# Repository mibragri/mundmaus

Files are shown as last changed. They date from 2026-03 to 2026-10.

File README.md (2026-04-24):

# MundMaus

**Mundgesteuerte Spieleplattform fuer Menschen mit Tetraplegie.**

Ein ESP32 mit Joystick und Drucksensor steuert browserbasierte Spiele — pusten statt klicken, Joystick statt Maus. Kein Internet, keine App. Nur WLAN und ein Browser.

Kosten: ~25 EUR | Aufbauzeit: ~30 Minuten | Nur der Drucksensor muss geloetet werden

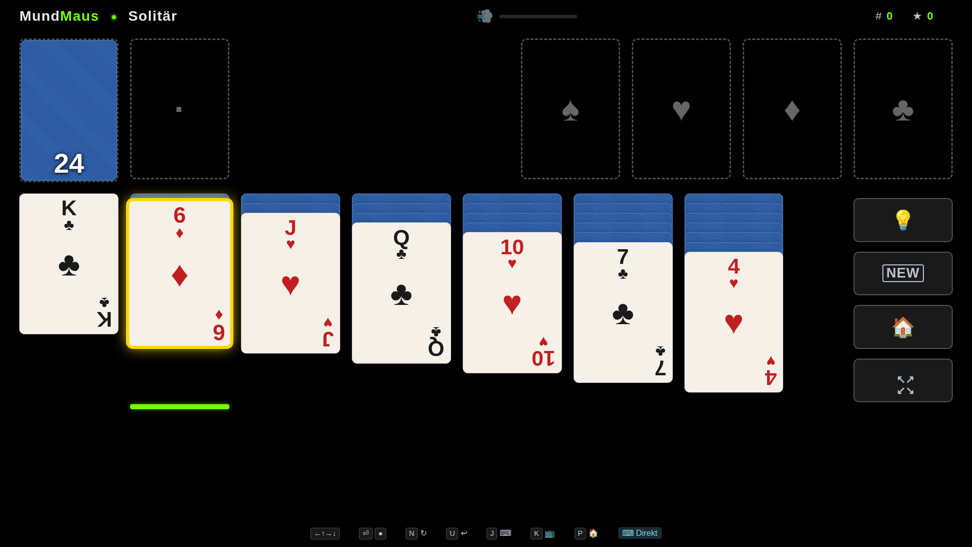
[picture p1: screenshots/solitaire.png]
Solitaire
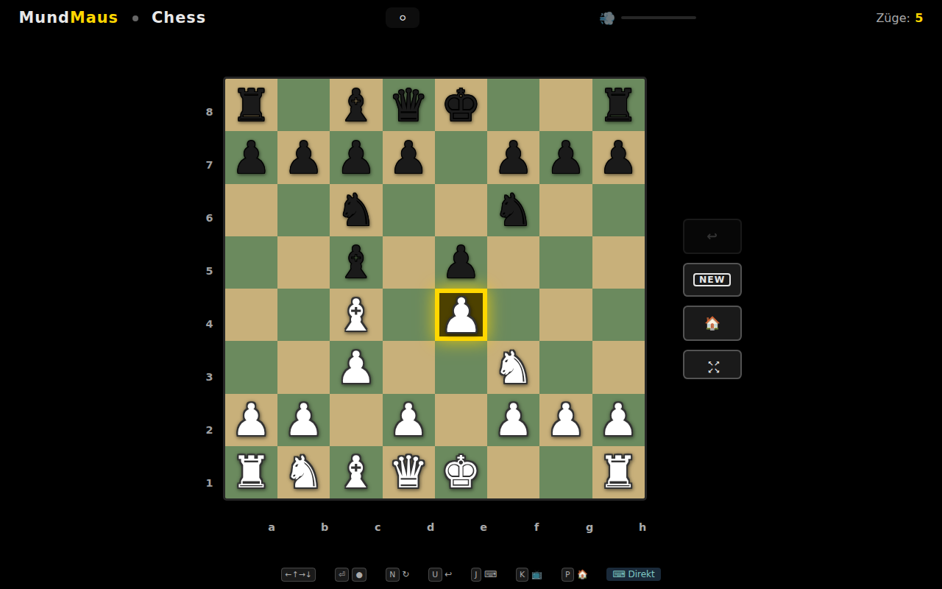
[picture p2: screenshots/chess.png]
Chess
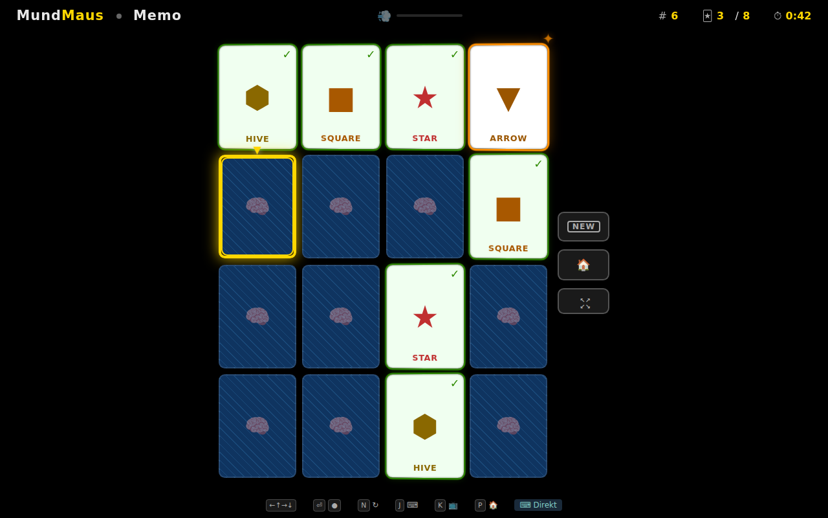
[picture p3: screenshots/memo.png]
Memo
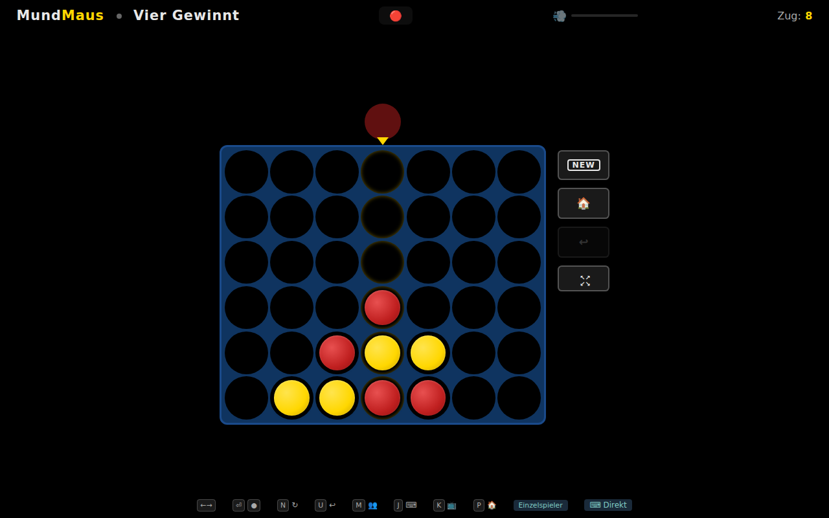
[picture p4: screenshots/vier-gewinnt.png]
Vier Gewinnt
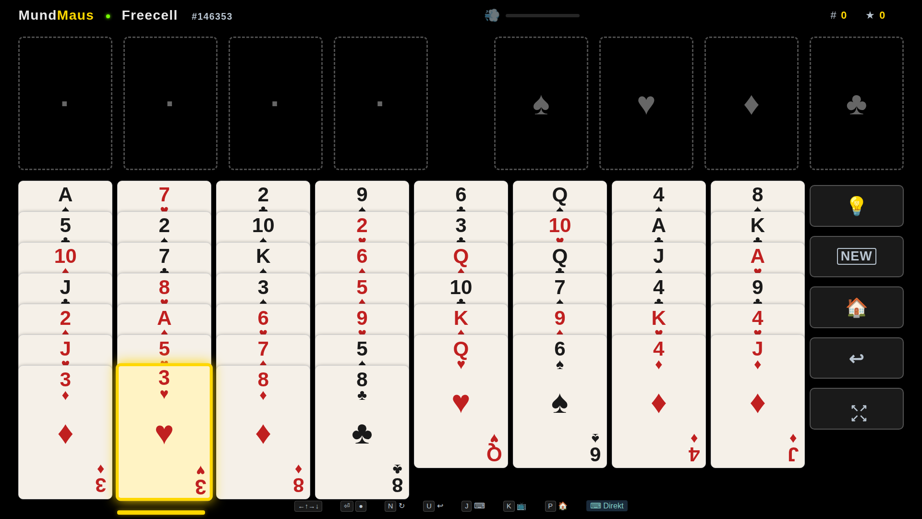
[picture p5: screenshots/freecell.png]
Freecell
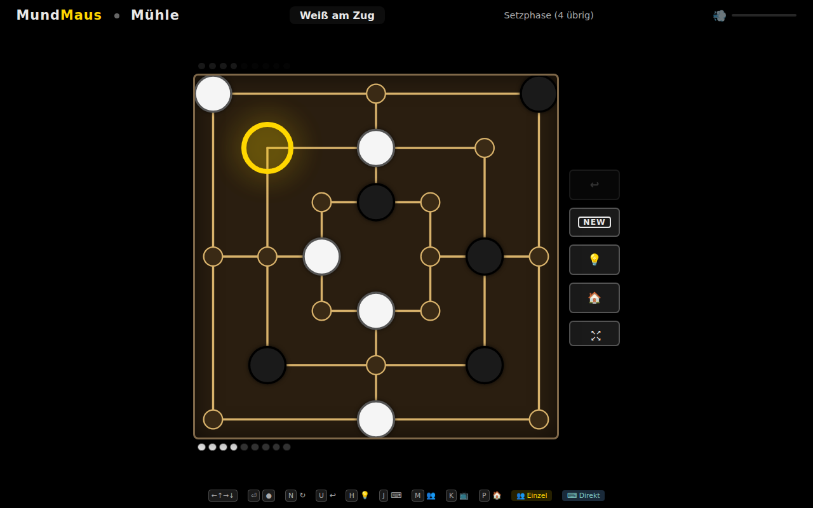
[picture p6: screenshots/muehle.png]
Mühle
     

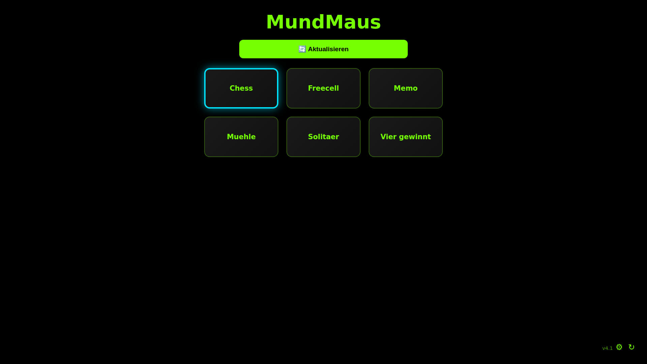
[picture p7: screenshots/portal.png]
Portal
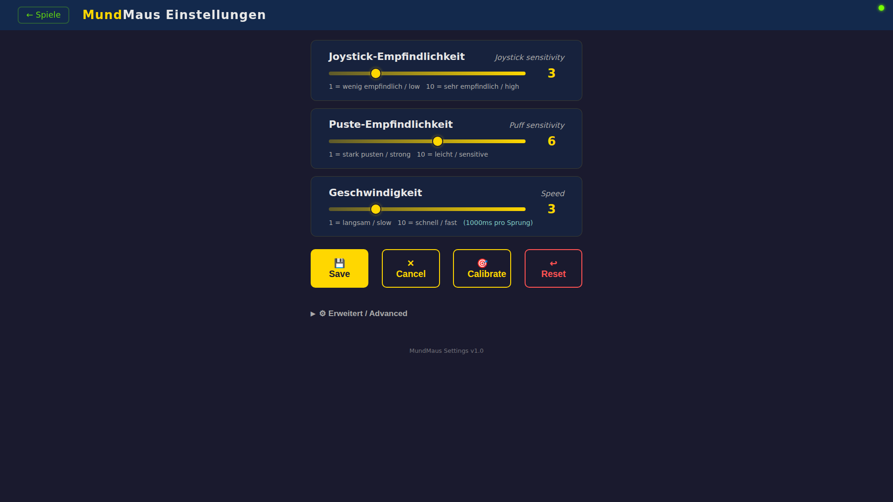
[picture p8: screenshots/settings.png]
Settings
 

## So funktioniert es

1. ESP32 liest Joystick (Lippe/Zunge) + Drucksensor (Pusten)
2. Sendet Befehle per WebSocket an den Browser
3. Browser zeigt Kartenspiele auf TV/Monitor
4. Alles laeuft lokal — kein Internet noetig

```
   Joystick ──┐
               ├── ESP32 ──── WiFi ──── Browser (TV/Monitor)
Drucksensor ──┘                          6 Spiele (Solitaer, Schach, Freecell, Memo, Muehle, Vier gewinnt)
```

## Spiele

| Spiel | Beschreibung |
|---|---|
| **Solitaire** | Klondike mit Undo, Auto-Solve, 3 Schwierigkeitsstufen |
| **Schach** | Gegen Computer, 4 Schwierigkeitsstufen |
| **Memo** | Memory-Spiel, 4 Feldgroessen |
| **Vier Gewinnt** | Connect Four gegen KI, 3 Schwierigkeitsstufen |
| **Freecell** | Freecell Solitaire mit Supermove und Auto-Complete |
| **Mühle** | Nine Men's Morris gegen KI, 3 Schwierigkeitsstufen, mit Multiplayer |

Alle Spiele sind barrierefrei: farbenblind-sichere Markierungen, Audio-Feedback, Kiosk-Modus fuer den Patienten, Keyboard-Fallback fuer Pfleger.

### Portal & Einstellungen

Das **Spiele-Portal** erscheint automatisch wenn man die ESP32-Adresse im Browser oeffnet — alle Spiele auf einen Blick, WiFi-Status, Software-Updates.

Die **Einstellungen** (⚙) erlauben Pflegern, Joystick-Empfindlichkeit, Puste-Staerke und Geschwindigkeit per Slider anzupassen — ohne technische Kenntnisse.

### OTA Auto-Update

Neue Spiele und Firmware-Updates werden automatisch ueber WiFi heruntergeladen. Beim Einschalten prueft der ESP32 ob Updates verfuegbar sind — ein Klick im Portal installiert sie. Bei fehlgeschlagenem Update: automatischer Rollback auf die vorherige Version.

### Verbindungs-Diagnose

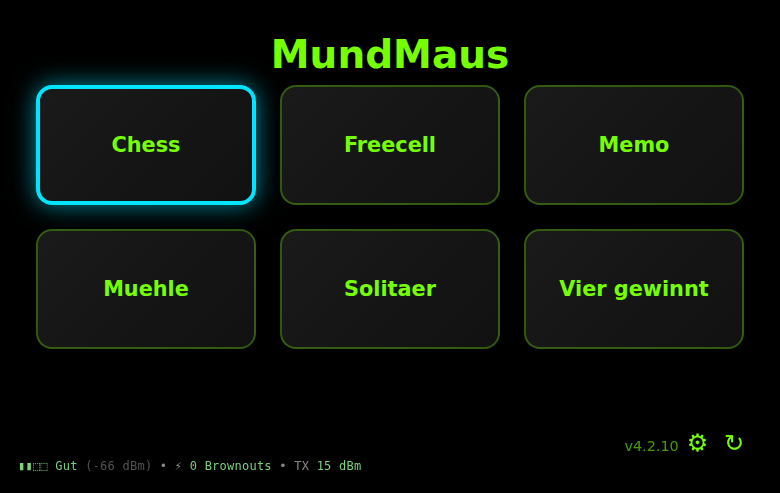
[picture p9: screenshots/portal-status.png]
Portal mit Status-Zeile


Unten links im Portal zeigt eine Status-Zeile jederzeit den Zustand des Geraets:

```
▮▮▮▯ Sehr gut (-63 dBm) • ⚡ 0 Brownouts • TX 15 dBm
```

- **Signal-Balken + Klartext** (Ausgezeichnet / Sehr gut / Gut / Ausreichend / Schwach) — keine dBm-Kenntnisse noetig, Detail in Klammern fuer Interessierte
- **Brownout-Zaehler** — zaehlt automatische Resets durch USB-Spannungsabfaelle. Bei > 0 erscheint ein Banner oben mit Handlungsempfehlung (kuerzeres/dickeres USB-Kabel, besseres Netzteil)
- **TX-Level** — aktueller WLAN-Sendepegel. Firmware reduziert automatisch in Stufen (15 → 13 → 11 → 8.5 → 7 dBm), falls Brownouts auftreten, um den Strom-Peak unter die kritische Schwelle zu druecken

Zusaetzlich loggt die Firmware Boot-/Connect-Events persistent auf Flash — abrufbar unter `http://<geraet>/api/wifi-log` (auch im AP-Fallback-Mode erreichbar). Damit lassen sich Cold-Boot-Probleme auch nachtraeglich diagnostizieren, ohne dass ein Laptop am Seriell-Port haengen muss.

## Was du brauchst

### Einkaufsliste

| # | Komponente | ca. Preis | Beispiel |
|---|---|---|---|
| 1 | ESP32-WROOM-32 DevKit *oder* ESP32-S3 DevKitC (mit Pins!) | ~8 EUR | AZ-Delivery ESP32 DevKitC V4 |
| 2 | KY-023 Joystick Modul | ~3 EUR | AZ-Delivery KY-023 |
| 3 | Drucksensor MPS20N0040D-S + HX710B | ~5 EUR | eBay/AliExpress "MPS20N0040D HX710B" |
| 4 | DuPont Jumper-Kabel (M-M + M-F) | ~3 EUR | 40 Stueck Set |
| 5 | Micro-USB Kabel (Daten, nicht nur Laden!) | ~3 EUR | Beliebig |
| 6 | Silikonschlauch 4mm Innendurchmesser | ~3 EUR | Aquarium-Zubehoer |

**Gesamtkosten: ~25 EUR** — DuPont-Kabel zusammenstecken. Nur der Drucksensor (HX710B) muss geloetet werden.

Die Firmware erkennt das Board beim Booten automatisch und setzt die Pin-Belegung entsprechend (ESP32-WROOM vs. ESP32-S3) — gleiches Binary, kein manuelles Umbauen.

> **Gehaeuse:** Ein 3D-druckbares Gehaeuse ist enthalten (`enclosure/`). Ohne 3D-Drucker: Komponenten einfach mit DuPont-Kabeln verbinden — fertig.

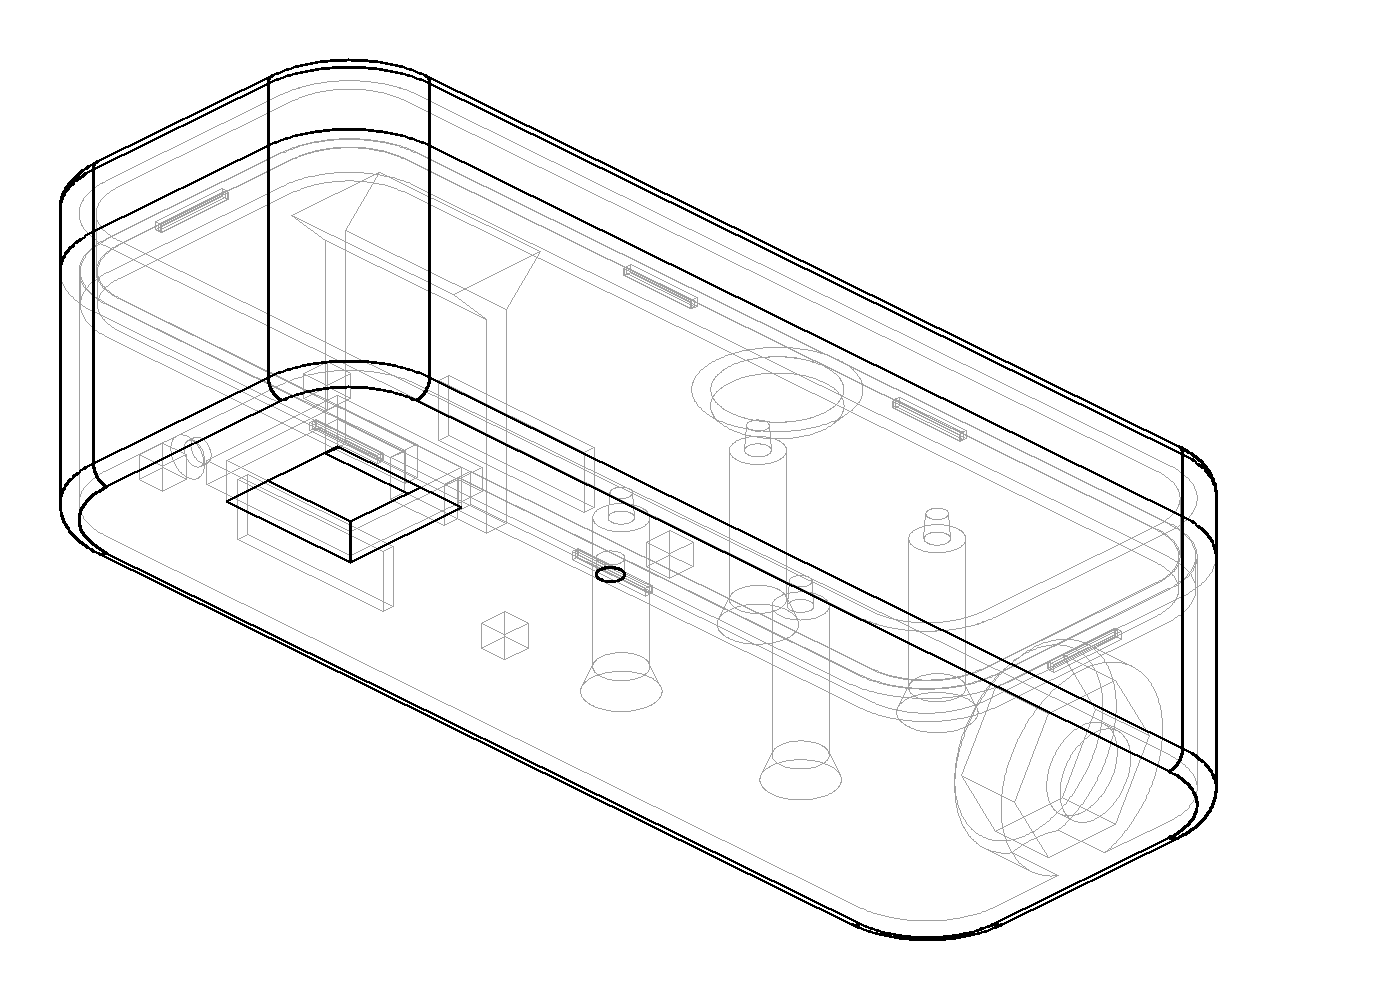
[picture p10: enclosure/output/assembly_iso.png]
Gehaeuse


### Mundstueck

Das 3D-druckbare Mundstueck sitzt auf dem Joystick-Stift. Ein Silikonschlauch geht seitlich ab und fuehrt zum Drucksensor — leichtes Pusten = Klick.

CAD-Modell (OnShape): [Mundstueck oeffnen](https://cad.onshape.com/documents/95d3a4d6faad26c25a2f7521/w/612dd5f1a9d3cf74ba406bb7/e/fc37b7a7abf844a33ef56714)

### Halterung

Das Gehaeuse wird in eine handelsueblliche **Mikrofonklemme** auf einem **Mikrofon-Bodenstaender** eingespannt (wie fuer Musiker). Der Staender steht neben dem Bett und positioniert den Joystick vor dem Mund des Patienten. Alternative: ein **Schwanenhals-Tischstaender** fuer kleinere Aufbauten.

> **Wichtig:** Das USB-Kabel muss ein **Datenkabel** sein, nicht nur ein Ladekabel! Datenkabel haben 4 Adern (2 Strom + 2 Daten), Ladekabel nur 2. Im Zweifel: wenn der Computer das ESP32 nicht erkennt, anderes Kabel probieren.

### Verkabelung

```
ESP32 DevKitC V4          KY-023 Joystick         HX710B + Drucksensor
┌─────────────────┐       ┌─────────────┐         ┌─────────────┐
│                 │       │             │         │             │
│  3V3 ───────────┼───────┤ +5V         │         │             │
│  GND ───────────┼───┬───┤ GND         │    ┌────┤ GND         │
│                 │   │   │             │    │    │             │
│  GPIO33 ────────┼───┼───┤ VRX         │    │    │             │
│  GPIO35 ────────┼───┼───┤ VRY         │    │    │             │
│  GPIO21 ────────┼───┼───┤ SW          │    │    │             │
│                 │   │   └─────────────┘    │    │             │
│  GPIO32 ────────┼───┼──────────────────────┼────┤ DATA        │
│  GPIO25 ────────┼───┼──────────────────────┼────┤ CLK         │
│  3V3 ──────────┼───┼──────────────────────┼────┤ VCC         │
│                 │   └──────────────────────┘    │             │
│       USB ──────┤                               │   Schlauch  │
│  (Strom+Daten)  │                               │   zum Mund  │
└─────────────────┘                               └─────────────┘
```

**Wichtig: Beide Sensoren an 3V3 anschliessen, NICHT an 5V!** Der ESP32 ADC vertraegt maximal 3.3V. Bei 5V-Versorgung koennen die Sensorausgaenge die ADC-Pins stoeren und falsche Joystick-Eingaben verursachen.

**Schlauch-Anschluss:** Silikonschlauch auf den Barb (Nippel) des Drucksensors stecken. Das andere Ende haelt der Patient im Mund. Leichtes Pusten = Klick.

> Detaillierte Pin-Tabelle (inkl. ESP32-S3 und optionales Display): siehe [TECHNICAL.md](TECHNICAL.md)

## Firmware aufspielen

Zwei Firmware-Optionen — gleiche Features, gleiche Spiele:

| | MicroPython | Arduino C++ |
|---|---|---|
| Fuer wen | Einsteiger, schnelles Testen | Fortgeschrittene, mehr Performance |
| RAM frei | ~80 KB | ~188 KB |
| OTA-Rollback | .bak-Dateien + Recovery-AP | Dual-Partition (automatisch) |
| Verzeichnis | `*.py` (Root) | `firmware/arduino/` |

### Option A: MicroPython (empfohlen fuer Einsteiger)

**Schritt 1:** Software installieren (einmalig, am Computer)
```bash
pip3 install esptool mpremote mpy-cross
```

**Schritt 2:** MicroPython auf den ESP32 flashen (einmalig)
```bash
# Firmware von micropython.org herunterladen:
# https://micropython.org/download/ESP32_GENERIC/
# Datei: ESP32_GENERIC-20251209-v1.27.0.bin

# ESP32 per USB anschliessen, dann:
esptool.py --chip esp32 --port /dev/ttyUSB0 erase_flash
esptool.py --chip esp32 --port /dev/ttyUSB0 --baud 460800 \
  write_flash -z 0x1000 ESP32_GENERIC-20251209-v1.27.0.bin
```

> **Windows:** Statt `/dev/ttyUSB0` den COM-Port verwenden (z.B. `COM3`). Im Geraetemanager nachschauen.

**Schritt 3:** MundMaus-Dateien hochladen
```bash
tools/upload-esp32.sh
```

Oder manuell:
```bash
mpremote connect /dev/ttyUSB0 cp boot.py main.py config.py :/
mpremote connect /dev/ttyUSB0 cp sensors.py server.py updater.py wifi_manager.py display.py :/
mpremote connect /dev/ttyUSB0 mkdir :www
mpremote connect /dev/ttyUSB0 cp games/solitaire.html games/chess.html games/memo.html games/settings.html games/vier-gewinnt.html games/freecell.html games/muehle.html :/www/
```

### Option B: Arduino C++ (mehr RAM, schneller)

```bash
cd firmware/arduino
pip install platformio

# Firmware kompilieren + flashen:
pio run -e esp32 -t upload

# Spieledateien flashen:
pio run -e esp32 -t uploadfs
```

## Erste Inbetriebnahme

1. **ESP32 per USB an Strom anschliessen** (USB-Ladegeraet oder Computer)
2. **Mit dem WLAN "MundMaus" verbinden** (Passwort: `mundmaus1`)
3. **Browser oeffnen:** `http://192.168.4.1`
4. **WLAN konfigurieren:** Im Portal das Heim-WLAN auswaehlen und Passwort eingeben
5. **ESP32 startet neu** und verbindet sich mit dem Heim-WLAN
6. **Beliebiges Geraet im gleichen WLAN** kann jetzt die Spiele oeffnen — entweder ueber die IP (im Seriell-Monitor) oder einfacher: **`http://mundmaus.local`** per mDNS. Funktioniert auf Apple-Geraeten nativ, auf Windows mit Bonjour Print Services, auf Linux mit avahi-daemon.

> **Fuer den TV:** Einen guenstigen Android-Stick (z.B. Xiaomi Mi TV Stick, ~30 EUR) an den TV anschliessen, Browser oeffnen, `mundmaus.local` eingeben. Oder einen alten Laptop/Tablet per HDMI an den TV.

## Einstellungen anpassen

Ueber das Portal (Zahnrad-Symbol ⚙) koennen Pfleger die Empfindlichkeit anpassen:

- **Joystick-Empfindlichkeit** — wie weit der Joystick bewegt werden muss
- **Puste-Staerke** — wie stark gepustet werden muss fuer einen Klick
- **Geschwindigkeit** — wie lang der Patient den Joystick halten muss bis der Cursor ein Feld weiterspringt (Standard 1000ms)

Aenderungen wirken sofort (Live-Preview). "Save" speichert dauerhaft, "Cancel" verwirft.

## Joystick-Auto-Kalibrierung

Jedes Einstecken der MundMaus startet mit einer automatischen Mittelpunkt-Kalibrierung:

1. Beim Boot liest die Firmware ~50 Joystick-Werte in einer halben Sekunde
2. Weicht der Joystick in dieser Zeit kaum ab (Spread < 300 ADC-Counts), wird der Mittelwert als neuer Nullpunkt uebernommen
3. Wackelt der Joystick zu stark (z.B. weil der Patient gerade das Mundstueck haelt), wird die Kalibrierung als ungueltig markiert — die Firmware uebernimmt den Wert trotzdem, damit ein klemmender Sensor nicht permanenten Ausschlag produziert

Konsequenz fuer den Pfleger: **Beim Anstecken das Mundstueck einen Moment loslassen.** Danach ist der Joystick zentriert — ohne Slider, ohne manuelles Trimmen. Falls der Cursor trotzdem in eine Richtung haengt: kurz MundMaus-Stecker ziehen, Joystick frei lassen, wieder einstecken — oder im Portal ueber den "Kalibrieren"-Button nachziehen.

## Kiosk-Modus fuer den Patient

Mit der Taste **K** wechselt jedes Spiel in den Kiosk-Modus: der Pfleger-Footer wird ausgeblendet, die grossen Action-Buttons (Neu / Zurueck / Tipp) bleiben sichtbar aber rechts vom Spielfeld, keine Menues sind erreichbar. So kann der Patient allein spielen, ohne versehentlich in Einstellungen oder Menues zu navigieren. Nochmal **K** blendet alles wieder ein.

## Keyboard-Shortcuts (Pfleger)

Fuer Pfleger, die die Spiele per Tastatur steuern oder testen wollen. Alle Spiele reagieren auf dieselbe Shortcut-Liste — sichtbar im Footer jedes Spiels:

| Taste | Funktion |
|---|---|
| Pfeiltasten | Navigation (links/rechts/oben/unten) |
| Leertaste / Enter | Auswaehlen / Klicken (wie Pusten) |
| **N** | Neues Spiel |
| **K** | Kiosk-Modus ein/aus |
| **J** | Joystick-Simulations-Modus (Charge-Mechanik statt sofortige Navigation) |
| **M** | Multiplayer-Modus (Schach, Vier gewinnt, Muehle) |

## Vorausschauende Navigation (Charge-Mechanik)

Damit der Patient die Kontrolle behaelt und nicht versehentlich ueber Karten hinwegspringt, nutzt die Navigation keine unsichtbaren Cooldowns sondern ein sichtbares Ladeprinzip:

1. Joystick in eine Richtung halten → das **Zielfeld** bekommt einen gruenen Rahmen der sich **im Uhrzeigersinn aufbaut** (wie ein Timer-Kreis, nur rechteckig)
2. Sobald der Rahmen geschlossen ist (~1 Sekunde), springt der Cursor dorthin
3. Joystick loslassen bevor der Rahmen voll ist → kein Sprung
4. **Analoge Joystick-Intensitaet**: leicht antippen = langsam laden, voll auslenken = schneller laden

Der Patient sieht also **immer vorher**, wohin der naechste Sprung geht und **wann** er passiert.

**Tastatur-Testmodus**: Mit **J** kann der Pfleger am Laptop zwischen Direktmodus (sofortige Navigation fuer Pflege) und Joystick-Simulation (Charge-Mechanik wie am Geraet) umschalten. Im Footer wird der aktuelle Modus als `⌨ Direkt` / `⌨ Sim` angezeigt.

**Multiplayer-Modus** (Schach, Vier gewinnt, Muehle): Mit **M** umschaltbar. Im Multiplayer spielt der Pfleger mit der Tastatur gegen den Patienten — beide nutzen die gleichen Eingabeformen, nur die KI wird durch den Pfleger ersetzt.

## Architektur

```
                        WebSocket :81
┌──────────────┐◄────────────────────────────►┌──────────────┐
│    ESP32     │         HTTP :80              │   Browser    │
│              │                               │   (TV/PC)    │
│  Joystick ───┤  ┌────────────────────────┐   │              │
│  Puff-Sensor─┤  │ Portal (/)             │──►│  Solitaire   │
│  WiFiManager │  │ Games (/www/*.html.gz) │   │  Schach      │
│  WS-Server   │  │ Settings (/www/settings│   │  Memo / ...  │
│  OTA Updater │  │ REST API (/api/*)      │   │  Settings    │
└──────────────┘  └────────────────────────┘   └──────────────┘
```

## Projektstruktur

```
mundmaus/
├── boot.py, main.py, config.py, ...  # MicroPython Firmware
├── sensors.py           # Joystick + Drucksensor (HX710B)
├── server.py            # HTTP/WebSocket Server + Portal
├── games/
│   ├── solitaire.html   # Klondike Solitaire
│   ├── chess.html        # Schach
│   ├── memo.html         # Memory/Memo
│   ├── vier-gewinnt.html # Vier Gewinnt (Connect Four)
│   ├── freecell.html     # Freecell Solitaire
│   ├── muehle.html       # Muehle (Nine Men's Morris)
│   └── settings.html     # Einstellungen
├── firmware/arduino/     # Arduino C++ Firmware (Alternative)
├── enclosure/            # 3D-Gehaeuse (CadQuery, druckfertig)
├── tools/                # Deploy- und Build-Scripts
├── website/              # mundmaus.de Webseite (separat)
└── TECHNICAL.md          # Hardware-Details, Protokolle, Raspberry Pi Setup
```

## FAQ

**Das ESP32 wird nicht erkannt (kein COM-Port):**
Anderes USB-Kabel versuchen! Viele Kabel sind reine Ladekabel ohne Datenleitungen.

**Die Spiele laden langsam:**
Normal beim ersten Laden — die Dateien werden komprimiert uebertragen (gzip). Danach schneller.

**Der Puff-Sensor reagiert nicht:**
Schlauch pruefen — ist er richtig auf dem Sensor-Nippel? Kein Knick im Schlauch? In den Einstellungen (⚙) die Puste-Empfindlichkeit erhoehen.

**Der Joystick springt:**
In den Einstellungen (⚙) die Empfindlichkeit reduzieren. Bei starkem WiFi-Ruckeln: ESP32 naeher an den Router stellen.

**Wie komme ich auf das ESP32 wenn ich die IP vergessen habe?**
`http://mundmaus.local` probieren (mDNS — funktioniert in allen Apple-Geraeten nativ). Wenn das nicht geht: ESP32 aus- und wieder einstecken. Wenn es kein WLAN findet, startet es automatisch den Hotspot "MundMaus" (Passwort: `mundmaus1`). Dann: `http://192.168.4.1`

**Das WLAN hat sich geaendert, wie sage ich das der MundMaus?**
Im Portal den Zahnrad-Button oeffnen und unter "WLAN" neue Credentials eintragen. Alternativ (wenn das alte WLAN gar nicht mehr da ist): einen POST an `http://mundmaus.local/api/wifi/reset` schickt — loescht gespeicherte Credentials, ESP32 rebootet in den AP-Fallback-Modus, dann wie bei der Erstinbetriebnahme neu konfigurieren.

**Was passiert wenn ein Firmware-Update schief geht?**
Zwei Sicherheitsnetze:
1. **Dual-Partition-Rollback** (Arduino-Firmware): ESP32 bootet nach einem fehlgeschlagenem Update automatisch auf die vorherige Version zurueck — transparent, ohne manuelles Eingreifen.
2. **Recovery-AP** (MicroPython-Firmware): Nach 3 fehlgeschlagenen Boot-Versuchen startet die Firmware den AP-Fallback "MundMaus" und stellt die Vorversion aus `.bak`-Dateien wieder her.

In beiden Faellen ist das Geraet ueber den Portal-Zugriff weiter erreichbar — kein Ziegelstein-Risiko beim Update.

## Mitmachen

Neue Spiele? Bug gefunden? Pull Requests willkommen! Alle Spiele sind einzelne HTML-Dateien in `games/` — HTML + CSS + JS in einer Datei, keine Build-Tools noetig.

Spiel-Design-Richtlinien: [games/STANDARDS.md](games/STANDARDS.md)

## Lizenz

AGPL-3.0 — siehe [LICENSE](LICENSE)

Basiert auf [mibragri/mouthMouse](https://github.com/mibragri/mouthMouse).

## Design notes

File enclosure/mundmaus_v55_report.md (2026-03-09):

# MundMaus v5.5 Enclosure
## Summary
v5.5 is a compact symmetric redesign. Key changes from v5.4c:
- **Removed adapter bay** — enclosure shrinks from 168 to 136 mm
- **New component order**: Mount(-X) → ESP32 → Joystick → Sensor(+X)
- **USB cable notch** on -Y wall at seam height; lid provides strain relief
- No internal USB cable routing; plug with lid open, close for retention

Component positions along X axis:
- Mic mount collar: -X wall (internal, -57.1 inner edge)
- ESP32 center: X=-28.0 (PCB -53.8 to -2.2)
- Joystick center: X=18.0 (platform -0.5 to 36.5)
- Sensor bracket: X=50.0 (bracket 38.0 to 62.0)
## Clearance Analysis
| Item | Value |
|---|---:|
| ESP32 end stop to collar | 3.35 mm |
| ESP32 right edge to joystick platform | 1.75 mm |
| Joystick platform to sensor bracket | 1.50 mm |
| Sensor bracket to +X inner wall | 3.00 mm |
| Joystick center Y | 5.00 mm |
| Joystick PCB overrun past +Y inner wall | 0.00 mm |
| Remaining +Y wall behind PCB relief | 3.00 mm |
| Front joystick posts to +Y wall | 6.50 mm |
| Sensor barb X offset from joystick | 32.00 mm |
| Sensor holder top to lid rim | 1.50 mm |
| Mount center on -X wall | Y=0.00 mm, Z=15.50 mm |
| Mount collar edge margin on 50 mm wall | 13.00 mm each side |
| USB cable notch X | -2.25 mm |
| USB cable notch wall | -Y |
| Vent slots wall | -Y |
| Pressure barb wall | +Y |
| Screw bosses | 3 (no +X+Y — sensor cable clearance) |
| Nearest -X screw boss clearance in Y | 0.50 mm |
## Changes vs v5.4c
| Feature | v5.4c | v5.5 |
|---|---|---|
| Shell width in X | 168 mm asymmetric | 136 mm symmetric |
| Adapter bay | +X, 32 mm | removed |
| Component order | Mount, Joystick, Sensor, ESP32+Adapter | Mount, ESP32, Joystick, Sensor |
| USB solution | +X adapter bay, direct plug | -Y cable notch + lid strain relief |
| ESP32 X position | 28.0 | -28.0 |
| Joystick X position | -15.0 | 18.0 |
| Sensor X position | 18.0 | 50.0 |
| +X+Y screw boss | standard corner | removed (sensor cable clearance) |
| Vent slot wall | -Y (fixed) | -Y |
| Pressure sensor | +Y wall side-mount, external barb | +Y wall side-mount, external barb |
| Joystick Y position | upper edge (Y=8.0) | upper edge (Y=5.0) |
| Pneumatic path | external: mouthpiece → +Y barb | external: mouthpiece → +Y barb |
## External Dimensions
- Base footprint: 136.0 x 50.0 mm
- Closed enclosure height: 41.0 mm
- Joystick protrusion above lid: 3.1 mm
## Print Notes
- Material: PETG preferred, PLA acceptable for quick fit checks
- Base orientation: floor-down, no support intended
- Lid orientation: flip 180 deg, ceiling-down
- USB cable: plug Micro-USB with lid off, route cable to -Y wall notch, close lid
- External hose path: mouthpiece → leftward (+X) outside enclosure → +Y wall barb
- The pressure sensor holder is a U-bracket; install sensor against +Y wall, lid retains from above
- The -X collar remains internal-only; the outer -X wall stays flat for the mic stand
- Suggested slicer baseline: 0.2 mm layer height, 4 walls, 25% gyroid, 240 C nozzle, 75 C bed, 40% fan

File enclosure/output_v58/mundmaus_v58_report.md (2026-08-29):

# MundMaus v5.8 Enclosure — Schraub-Verschluss (Spax 3.5x20)
## Summary
v5.8 ersetzt den Detent-Klick-Verschluss aus v5.7 durch eine echte Schraub-
verbindung mit 4 Spax 3.5x20 Senkkopf-Spanplattenschrauben in den Eck-
Innenbereichen. Detent-Ridges/Grooves vollständig entfernt.

Geometrie:
- 4 Schraubsäulen im Base bei (±58, ±18.0), D=6.0mm,
  Vorbohr-Loch 2.5mm.
- 4 hängende Säulen im Lid (gleiche XY-Position) mit Durchgangsloch 4.0mm
  und Senkung 7.5mm × 2.1mm tief an der Lid-Außenseite.
- ESP-Side-Guide-Rails von ESP_L*0.4 (21.8mm) auf 14.0mm gekürzt — Rails standen
  sonst im Weg der +X- und +Y-Eck-Säulen.
- Lip (3.0mm) bleibt zur Zentrierung beim Zusammenbau und für Staubdichtigkeit.

## Schrauben-Tiefenrechnung
| Strecke | Wert |
|---|---:|
| Schraubenlänge gesamt | 20.0 mm |
| Senkung im Lid (Kopf bündig, im Lid-Korpus enthalten) | 2.1 mm |
| Lid-Korpus durchquert (Decke + Lip-Hänger) | 12.0 mm |
| Spiel Lid-Hänger zu Säulen-Top | 0.2 mm |
| Eindringtiefe in Base-Säule (tatsächlich) | 7.8 mm |
| Summe (= Schraubenlänge) | 20.0 mm |
| Säulenoberkante Z (base coords) | 26.8 mm |
| Spiel Säulen-Top zu Lid-Hänger-Boden | 0.2 mm |
| Boden-Reserve unter Bohrung | 16.8 mm |
| Säulen-Kollisions-Abstand zur Eckkurve | 1.61 mm |

## Komponenten-Layout (unverändert von v5.7)
- Mic mount collar: -X wall (internal, -58.1 inner edge)
- Joystick center: X=-19.0 (platform -37.5 to -0.5)
- ESP32 center: X=31.0 (PCB 3.8 to 58.2, USB at -X end)
- Sensor shelf: +X inner wall, shelf X=61.0 to 66.0, Z=5.5 to 25.5

## Clearance Analysis
| Item | Value |
|---|---:|
| Lip zone bottom | 27.0 mm |
| Sensor PCB top to lip zone | 1.5 mm |
| Mic collar to joystick platform | 20.60 mm |
| ESP32 right edge to +X inner wall | 7.80 mm |
| Sensor bottom Z to ESP32 PCB top Z | -0.7 mm |
| Hold-down wall gap (lid closed) | 1.0 mm |
| Barb hole diameter | 2.8 mm (press-fit) |
| Pressure barb wall | +X |
| Lid attachment | 4 Schrauben Spax 3.5x20 Senkkopf |

## Changes vs v5.7
| Feature | v5.7 | v5.8 |
|---|---|---|
| Verschluss | Detent-Klick (7 Ridges/Grooves) | 4× Schraube Spax 3.5x20 |
| RIDGE_H/GROOVE_D | 0.6 / 0.55 mm | entfallen |
| Base-Säulen | — | 4× D=6mm, h=24.8mm, Bohrung 2.5mm |
| Lid-Säulen-Hänger | — | 4× D=6mm, h=10.0mm, Senkung 7.5/2.1 |
| ESP-Side-Rails | 21.8 mm | 14.0 mm |
| Base STL | v5.6 unchanged | NEU (Säulen + kürzere Rails) |
| Lid STL | v5.7 | NEU (Hänger + Senkungen, ohne Detents) |

## External Dimensions
- Base footprint: 136.0 x 50.0 mm
- Closed enclosure height: 39.0 mm
- Joystick protrusion above lid: 2.6 mm

## Print Notes
- Material: PETG preferred, PLA acceptable for quick fit checks
- Base orientation: floor-down, no support intended
- Lid orientation: flip 180 deg, ceiling-down. Senkungen liegen damit an der Druckplatte;
  die 40°-Konuswand druckt support-frei (Material drumherum, nicht darüber).
- Schrauben: 4× Spax/Spanplattenschraube 3.5×20 mm Senkkopf, Torx oder Kreuzschlitz.
  In PETG selbstschneidend — kein Brass-Insert nötig.
- Anzugsmoment: handfest, nicht überdrehen (PETG-Säulenwand 1.75mm).
- USB cable: plug Micro-USB with lid off, route cable to -Y wall notch, close lid.
- External hose path: mouthpiece -> +X wall barb (straight run, minimal bending).
- Pressure sensor: place PCB flat against +X inner wall, nipple through barb hole, lid retains from above.
- The -X collar remains internal-only; the outer -X wall stays flat for the mic stand.
- Suggested slicer baseline: 0.2 mm layer height, 4 walls, 25% gyroid, 240 C nozzle, 75 C bed, 40% fan.

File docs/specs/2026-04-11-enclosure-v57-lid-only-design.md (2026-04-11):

# MundMaus Enclosure v5.7 — Lid-Only Fix

## Summary

Two changes to the v5.6 lid. **Base unchanged — only the lid needs to be reprinted.**

1. **Lip reduction** (LIP_H 4.0 → 3.0 mm): fixes collision between lid inner lip and pressure sensor PCB top
2. **Ridge strengthening** (RIDGE_H 0.5 → 0.6 mm) + alignment shift (RIDGE_Z 2.0 → 1.0 mm): 20% more detent retention, aligned with existing grooves in the base

## Problem Statement (v5.6 observed)

Two issues prevented the lid from latching properly:

1. **Lid won't close fully near the pressure sensor.** The lid's inner lip enters the base cavity from z=26 to z=30 (LIP_H=4). The sensor PCB top sits at z=25.5 (PRES_POS_Z=15.5 center + 10 half-height). The theoretical margin is 0.5mm but in practice the lip collides with the sensor assembly, preventing full lid seating.

2. **Detent ridges don't engage.** Because the lid sits ~0.5-1mm too high (due to #1), the ridges on the lid lip never align with the grooves in the base cavity wall. The lid sits on top of the collision with no retention at all.

Root cause of #2 is #1. Fix #1 and the ridges may engage correctly. But we also slightly strengthen the ridges for extra margin, since reprinting is cheap.

## Design

### Change 1: Lip reduction (LIP_H 4.0 → 3.0 mm)

- **Parameter:** `LIP_H = 3.0` (was 4.0)
- **Effect in base coords:** lip zone moves from z=26-30 to z=27-30. Sensor top at z=25.5 now has 1.5mm clearance (was 0.5mm theoretical, negative in practice).
- **Structural impact:** lid lip is 1mm shorter → slightly weaker engagement with base cavity. Compensated by detent strengthening below.
- **LIP_T (lip wall thickness)** stays at 1.8mm — flex characteristics unchanged.
- **LIP_GAP** stays at 0.15mm.

### Change 2: Ridge strengthening + alignment (RIDGE_H 0.5 → 0.6, RIDGE_Z 2.0 → 1.0)

The detent ridges on the lid lip need to (a) be stronger and (b) still align with the existing grooves in the base (which are at fixed z=28 in assembly coords).

**Alignment math:**
```
Ridge Z in assembly coords = EXT_H_BASE - LIP_H + RIDGE_Z
```

Existing base grooves:
```
groove_z = 30 - 4 + 2 = 28 mm  (v5.6 base, unchanged)
```

New lid ridges must match:
```
ridge_z = 30 - 3 + 1 = 28 mm  ✓ (with LIP_H=3, RIDGE_Z=1)
```

**Parameters:**
- **`RIDGE_H = 0.6`** (was 0.5): 20% taller, 20% more retention force
- **`RIDGE_Z = 1.0`** (was 2.0): ridge position within the lip, measured from lip bottom edge. Required to maintain alignment with existing grooves after LIP_H reduction.
- **`RIDGE_W = 0.8`** unchanged (ridge width along Z axis of lip, fits in 1mm-wide GROOVE_W)
- **`RIDGE_LEN = 10.0`** unchanged (ridge pad length along wall)

**Interference with existing grooves:** new `RIDGE_H=0.6` > existing `GROOVE_D=0.55`. 0.05mm interference at rest. PETG lip flex absorbs this easily; creates small preload on the latch, slightly improving hold.

### What does NOT change

- Base (`make_base()`) — zero code changes, existing prints work
- `GROOVE_D = 0.55`, `GROOVE_W = 1.0` — base grooves unchanged
- Groove positions in base (7 pads at same locations)
- Ridge positions in XY (same 7 ridge pads matching the groove locations)
- `HOLD_DOWN_CLEARANCE` (ESP32 hold-down wall)
- Pressure sensor mount, barb hole, all other base features

## Code Changes

File: copy `enclosure/mundmaus_v56_enclosure.py` → new file `enclosure/mundmaus_v57_enclosure.py` (keep v56 alongside, consistent with how v55 and v56 coexist in the repo).

Three constant changes:

```python
LIP_H, LIP_T, LIP_GAP = 3.0, 1.8, 0.15   # was 4.0
```

```python
RIDGE_H = 0.6        # was 0.5, 20% more retention
RIDGE_Z = 1.0        # was 2.0, realigned with existing grooves after LIP_H reduction
```

Plus:
- Update docstrings/comments in `make_lid()` referencing LIP_H values
- Update report text in the report-generation section (reference LIP_H, RIDGE_H, RIDGE_Z)
- Verify the `_LIP_CLEARANCE_CHECKS` guard still passes with `LIP_ZONE_BOTTOM = 27` (was 26)

**Expected guard re-check:**
- Sensor PCB top: 25.5mm vs new limit 27.0mm → margin 1.5mm ✓
- Mic collar top: 25.5mm vs 27.0mm → margin 1.5mm ✓
- Joystick PCB top: computed vs 27.0mm → likely still fine, verify on build

## Testing

No unit tests — this is pure CAD parameter change. Validation is geometric:

1. Script runs without errors
2. `_LIP_CLEARANCE_CHECKS` guard passes (sensor/mic/joystick all below new z=27 limit)
3. Rendered lid STL shows: 3mm lip, 0.6mm ridges at the correct Z, matching groove positions
4. Physical test: new lid closes on existing base without collision, ridges engage with audible/tactile click, lid cannot be lifted without deliberate prying

## Assembly Order (unchanged)

1. ESP32 in guide rails
2. Sensor PCB flat against +X wall, nipple through barb hole
3. Joystick on pillars
4. Lid closes — ridges snap into grooves

## Risks

- **0.05mm interference** (RIDGE_H=0.6, GROOVE_D=0.55): if PETG batch is unusually stiff or print tolerances stack unfavorably, the lid may be hard to close. Mitigation: if too tight, reduce RIDGE_H to 0.58 or 0.55 (matching groove exactly, zero interference but still 10% stronger than v5.6).
- **Guard check must pass:** the new LIP_ZONE_BOTTOM=27 is still above all internal features. If the build fails the guard (e.g. joystick at 27.0 exactly), we need to adjust position or accept the warning.
- **20% more retention may still not be enough:** if the lid still pops off after this change, next escalation is cantilever snap-fit clips (separate spec, base would need redesign).

## Files Changed

- `enclosure/mundmaus_v56_enclosure.py` → `mundmaus_v57_enclosure.py` (copy, edit 3 constants, update report text)
- No base STL regeneration needed
- New lid STL to be printed and tested on existing base

## Non-Goals

- Cantilever snap-fit clips (deferred — only if this fix is insufficient)
- Base redesign
- Pressure sensor or ESP32 hold-down changes
- Screws/heat-set inserts

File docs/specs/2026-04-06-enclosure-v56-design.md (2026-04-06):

# MundMaus Enclosure v5.6 — Design Spec

## Summary

Three changes to the v5.5 enclosure:

1. **Pressure sensor relocation** from +Y wall to +X wall (barb + holder + breakout board)
2. **ESP32 hold-down wall fix** in lid (1mm shorter, properly calculated)

~~3. ESP32 retention lip~~ — dropped: would need support printing, ESP32 is already held by guide rails + lid wall. Can add vertical clip later if needed.

## Sensor Hardware Reference

**MPS20N0040D-S + HX710B Breakout Board** (verified from datasheet + product photo):
- Red PCB: ~20mm x 15mm
- MPS20N0040D-S sensor in upper-right area of PCB, pressure nipple pointing UP (perpendicular to PCB surface)
- HX710B ADC in center of PCB
- 4-pin header at bottom edge: VCC, OUT, SCK, GND
- Nipple is NOT centered on the PCB — offset toward upper-right corner
- PCB thickness: ~1.6mm, sensor body ~5mm above PCB, nipple ~3mm above sensor
- Nipple outer diameter: ~3mm (barb hole Ø2.8mm for press-fit)

## Change 1: Pressure Sensor to +X Wall

### Current State (v5.5)
- Sensor mounted on +Y wall shelf at X=42
- Barb hole Ø3.0mm through +Y outer wall
- Holder function defined but NOT called in `make_base()`
- Barb port IS cut (`_cut_pressure_barb_port` is in the build pipeline)

### New Design (v5.6)
- **Mounting:** PCB lies FLAT against +X inner wall, component side (with sensor + nipple) facing the wall. Nipple pokes through the Ø2.8mm barb hole to the outside. Back side (solder pads, wiring) faces into the enclosure.
- **Depth into enclosure: only 5mm** (PCB 1.6mm + sensor body clearance + wiring space)
- **Sensor position on +X wall:**
  - Center Y = 0.0 (symmetric on wall)
  - Center Z = 18.0 (same as v5.5)
  - PCB footprint on wall: 20mm (Z) x 15mm (Y)
  - Z range: 8.0 to 28.0
  - Y range: -7.5 to +7.5
  - Inner edge at X = 66.0 - 5.0 = 61.0
- **ESP32 clearance:** sensor assembly bottom Z=8.0, ESP32 PCB top Z=6.2 -> 1.8mm vertical gap. Sensor inner edge X=61, ESP32 right edge X=62.2 -> 1.2mm overlap in X but at different Z heights, no physical conflict.
- **Barb hole:** Ø2.8mm through +X outer wall (was Ø3.0mm on +Y wall — tighter for press-fit). Chamfer on exterior side (Ø5.0mm entry). Barb hole position = sensor nipple center on the wall, offset from PCB center (needs measurement from actual board, estimated ~5mm from PCB top edge, ~4mm from right edge).
- **Holder:** L-bracket or shelf on +X inner wall. Bottom ledge supports PCB weight, optional side clips. Lid retains from above (same principle as v5.5).
- **Hose routing:** external, from mouthpiece to +X wall barb (was +Y wall).

### Code Changes
- `PRES_POS_X` removed (sensor is against +X wall, position derived from INNER_POS_X)
- `PRES_MOUNT_DEPTH = 5.0` (depth from +X inner wall into enclosure)
- `PRES_POS_Y = 0.0` (centered on wall)
- `PRES_POS_Z = 18.0` (kept from v5.5)
- `PRES_BARB_HOLE_D = 2.8` (was 3.0)
- Rewrite `_add_pressure_sensor_mount()`: flat mount against +X inner wall
- Rewrite `_cut_pressure_barb_port()`: hole through +X wall (YZ workplane at X=+OUTER_POS_X)
- Add `_add_pressure_sensor_mount` to `make_base()` pipeline (currently missing!)
- Remove old +Y barb cut
- Update report text

## Change 2: ESP32 Hold-Down Wall Height Fix

### Current State (v5.5)
```python
esp_pcb_top_z = FLOOR_T + ESP_STANDOFF_H + ESP_H  # = 6.2mm
rib_bot_z = -(EXT_H_BASE - esp_pcb_top_z)          # = -23.8mm (lid coords)
rib_height = LID_INNER_H - rib_bot_z               # = 30.8mm
```
Wall reaches EXACTLY to ESP32 PCB top when lid is fully closed. Zero tolerance.
Result: wall bottoms out on PCB before detent ridges can engage -> lid won't close.
User has filed down the wall by hand to make it work.

### New Design (v5.6)
```python
HOLD_DOWN_CLEARANCE = 1.0  # mm gap between wall bottom and ESP32 PCB top
rib_bot_z = -(EXT_H_BASE - esp_pcb_top_z - HOLD_DOWN_CLEARANCE)  # = -22.8mm
rib_height = LID_INNER_H - rib_bot_z  # = 29.8mm (1mm shorter)
```
Wall ends 1.0mm above ESP32 PCB top when lid is fully closed. Provides:
- Enough clearance for print tolerances, PETG shrinkage, elephant foot
- Space for detent ridges to fully engage before any PCB contact
- PCB can still only lift 1mm max (guide rails prevent lateral movement)

### Code Changes
- Add `HOLD_DOWN_CLEARANCE = 1.0` constant near ESP32 section
- Update `rib_bot_z` calculation in `make_lid()` to subtract clearance

## ~~Change 3: ESP32 Retention Lip~~ — DROPPED

Dropped: horizontal lip needs support printing, not worth the complexity. ESP32 already secured
by guide rails (lateral) + lid hold-down wall (vertical, now with 1mm clearance). If ESP32 lifts
without lid in practice, can add a vertical clip later (no support needed for vertical features).

## Assembly Order

1. ESP32 slides into guide rails
2. Pressure sensor breakout board placed flat against +X wall from inside, nipple through barb hole
3. Joystick seats on pillars (USB cable first if needed)
4. Lid closes — hold-down wall (1mm shorter) provides retention for ESP32, lid retains sensor

## Clearance Summary (v5.6)

| Item | Value |
|---|---:|
| ESP32 right edge to +X inner wall | 3.8 mm |
| Sensor assembly depth from +X wall | 5.0 mm |
| Sensor inner edge X | 61.0 mm |
| ESP32 right edge X | 62.2 mm |
| X overlap (different Z, no conflict) | 1.2 mm |
| Sensor bottom Z to ESP32 PCB top Z | 1.8 mm |
| Hold-down wall gap (lid closed) | 1.0 mm |
| Barb hole diameter | 2.8 mm (press-fit) |

## Files Changed

- `enclosure/mundmaus_v55_enclosure.py` -> rename to `mundmaus_v56_enclosure.py`
  - Constants: PRES_MOUNT_DEPTH, PRES_POS_Y/Z, PRES_BARB_HOLE_D, HOLD_DOWN_CLEARANCE
  - Functions: `_add_pressure_sensor_mount()`, `_cut_pressure_barb_port()`, lid hold-down calc
  - Pipeline: add sensor mount to `make_base()`, remove old +Y barb
  - Report text updates

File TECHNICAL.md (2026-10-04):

# MundMaus — Technische Referenz

Ergaenzung zur [README.md](README.md). Hier stehen Hardware-Details, Protokolle,
Firmware-Interna und Raspberry-Pi-Setup die fuer Entwickler und fortgeschrittene
Einrichtung relevant sind.

---

## Pin-Belegung

Die Firmware erkennt das Board automatisch (`config.py` / `config.h`).

| Funktion | ESP32-WROOM (V4) | ESP32-S3 (N16R8) | Hinweis |
|---|---|---|---|
| Joystick VRX | **GPIO33** | GPIO1 | ADC1 |
| Joystick VRY | **GPIO35** | GPIO2 | ADC1 |
| Joystick SW | **GPIO21** | GPIO42 | Digital, Pull-Up |
| Puff DATA | **GPIO32** | GPIO4 | Digital (HX710B) |
| Puff CLK | **GPIO25** | GPIO5 | Digital (HX710B) |
| Display A0 | **GPIO2** | GPIO6 | Data/Command |
| Display RST | GPIO14 | GPIO14 | Reset |
| Display CS | GPIO17 | GPIO17 | SPI CS |
| Display SCK | GPIO18 | GPIO18 | SPI CLK |
| Display SDA | GPIO23 | GPIO23 | SPI MOSI |

> ESP32-S3 hat keine GPIO33-39. Board-Erkennung via `sys.implementation._machine`.

### Komplettes Pinout (ESP32-WROOM DevKitC V4)

```
                 ESP32-WROOM-32 DevKitC V4
                 +----------------------+
                 |     [USB Micro-B]    |
                 +----------------------+
           3.3V -| 3V3              GND |- GND (alle GND)
                 |                      |
                 | GPIO33         GPIO21|- Joystick SW
                 | (Joystick VRx)       |
                 | GPIO35         GPIO23|- Display SDA
                 | (Joystick VRy)       |
                 | GPIO32         GPIO18|- Display SCK
                 | (Puff DATA)          |
                 | GPIO25         GPIO17|- Display CS
                 | (Puff CLK)           |
                 | GPIO2          GPIO14|- Display RST
                 | (Display A0)         |
                 | ...             ...  |
                 +----------------------+

Stromversorgung:
  3.3V ──┬── KY-023 "+5V" (Label ignorieren, 3.3V reicht!)
         ├── HX710B VCC
         └── ST7735 VCC (optional)
  GND ──┬── KY-023 GND
        ├── HX710B GND
        └── ST7735 GND (optional)
```

---

## Verkabelung

### Joystick KY-023

```
KY-023          ESP32-WROOM
---------       -----------
GND      ────── GND
+5V      ────── 3.3V  (NICHT 5V — 3.3V reicht, ADC-Werte passen)
VRx      ────── GPIO33
VRy      ────── GPIO35
SW       ────── GPIO21
```

Mechanisch: PCB 34×26mm, vier M4-Bohrungen im Raster **26.67×20.32mm** — diese
Masse legen die Saeulenpositionen im 3D-Gehaeuse fest.

### Drucksensor MPS20N0040D-S + HX710B

```
HX710B Board    ESP32-WROOM
------------    -----------
VCC      ────── 3.3V
GND      ────── GND
DATA     ────── GPIO32
CLK      ────── GPIO25
```

Silikonschlauch (ID 4mm) vom Mundstueck → seitlich am Gehaeuse entlang → auf
den Barb (Nippel) des Drucksensors stecken.

### Display ST7735 (optional)

```
ST7735          ESP32-WROOM
------          -----------
VCC      ────── 3.3V
GND      ────── GND
SDA      ────── GPIO23 (MOSI)
SCK      ────── GPIO18 (SCK)
CS       ────── GPIO17
A0/DC    ────── GPIO2
RESET    ────── GPIO14
```

---

## Mundstueck

Das Mundstueck wird separat in OnShape verwaltet:

**CAD-Modell:** <https://cad.onshape.com/documents/95d3a4d6faad26c25a2f7521/w/612dd5f1a9d3cf74ba406bb7/e/fc37b7a7abf844a33ef56714>

Es sitzt auf dem Joystick-Stift und hat einen seitlichen Schlauch-Abgang
(Richtung +X / links vom Patienten). Der Silikonschlauch laeuft aussen am
Gehaeuse zum Drucksensor. Der Schlauch darf nicht stark gebogen werden — das
zieht am Joystick und beeintraechtigt die Navigation.

---

## Firmware-Architektur

Zwei gleichwertige Firmware-Varianten mit identischem Feature-Set:

### MicroPython (asyncio)

```
asyncio.run(async_main)
  ├── sensor_loop()    – 50 Hz, Joystick + Puff → WebSocket
  ├── server_loop()    – 100 Hz, HTTP accept + WS accept + WS read
  └── display_loop()   – 0.2 Hz, ST7735 TFT update (optional)
```

Module: `boot.py`, `main.py`, `config.py`, `sensors.py`, `server.py`,
`wifi_manager.py`, `updater.py`, `display.py`

### Arduino C++ (FreeRTOS)

```
Core 0: AsyncTCP + HTTP Server + WebSocket + OTA
Core 1: Sensor-Task (50 Hz Joystick + Puff) + WDT-Heartbeat
```

Quellen: `firmware/arduino/src/`

### Klassen / Module

#### CalibratedJoystick (`sensors.py` / `sensors.cpp`)

ADC-basierter Joystick mit Drift-Kompensation.

- `calibrate(samples=50)` — Mittelwert bei Ruheposition → echte Mitte
- `read_centered()` → `(dx, dy)` relativ zur Mitte, Deadzone angewendet
- `get_direction()` → `left|right|up|down|None`
- `poll_navigation()` — mit Repeat-Timer (konfigurierbar)
- `is_idle()` → True wenn nahe Mitte (triggert Auto-Rekalibrierung nach 10s)

**Drift-Problem:** Billige KY-023 haben thermischen ADC-Drift. Geloest durch
Auto-Kalibrierung beim Boot + Auto-Rekalibrierung nach Idle.

#### PuffSensor (`sensors.py` / `sensors.cpp`)

HX710B 24-bit ADC Bit-Bang-Reader fuer MPS20N0040D-S.

- `calibrate_baseline(samples=30)` — Ruhedruck-Kalibrierung
- `read_normalized()` → `0.0` bis `1.0`, gleitender Durchschnitt
- `detect_puff()` → True bei Threshold + Cooldown
- `get_level()` → aktueller Pegel fuer UI-Anzeige

**Limitierung:** Nur Pusten (Ueberdruck), kein Saugen. Fuer Sip-and-Puff
waere ein Differenzdrucksensor (MPXV7002DP) noetig.

#### WiFiManager (`wifi_manager.py` / `wifi_manager.cpp`)

```
Boot-Flow:
  load_credentials()     → liest wifi.json / NVS
       │
       ├─ Credentials da → connect_station(timeout=10s)
       │                         │
       │                    ├─ OK → Station-Modus (Router-IP)
       │                    └─ Fail → start_ap()
       │
       └─ Keine Credentials → start_ap()

AP-Modus:
  SSID: "MundMaus"  |  Pass: "mundmaus1"  |  IP: 192.168.4.1
```

#### MundMausServer (`server.py` / `web_server.cpp`)

Kombinierter HTTP File-Server + WebSocket Server.

---

## Konfigurationsparameter

Definiert in `config.py` (MicroPython) / `config.h` (Arduino). Zur Laufzeit
aenderbar ueber die Settings-Seite im Browser (⚙ im Portal).

| Parameter | Default | Beschreibung |
|---|---|---|
| `DEADZONE` | 150 | ADC-Einheiten um Joystick-Mitte ignorieren |
| `NAV_THRESHOLD` | 450 | ADC-Wert ab dem Richtung erkannt wird |
| `NAV_REPEAT_MS` | 400 | Wiederholrate bei gehaltenem Joystick |
| `PUFF_RAW_THRESHOLD` | 75000 | Rohwert ab dem Puff erkannt wird |
| `PUFF_COOLDOWN_MS` | 400 | Mindestzeit zwischen zwei Puffs |
| `SENSOR_POLL_MS` | 20 | Sensor-Abtastintervall (50 Hz) |
| `USE_DISPLAY` | False | ST7735 TFT ein/ausschalten |
| `RECAL_IDLE_MS` | 10000 | Auto-Rekalibrierung nach Idle |

---

## HTTP API

Beide Firmware-Varianten implementieren dieselben Endpoints.

| Endpunkt | Methode | Beschreibung |
|---|---|---|
| `/` | GET | Spiele-Portal (listet alle Spiele, WiFi-Status, Updates) |
| `/www/<datei>` | GET | Spieldatei aus www/ (gzip-komprimiert auf LittleFS) |
| `/api/info` | GET | `{board, version, free_ram, ...}` |
| `/api/wifi` | GET | WiFi-Status `{mode, ssid, ip, connected}` |
| `/api/wifi` | POST | Credentials speichern `{ssid, password}` → Reboot |
| `/api/scan` | GET | WLAN-Scan `{networks: ["SSID1", ...]}` |
| `/api/settings` | GET | Aktuelle Konfig-Werte (Deadzone, Threshold, ...) |
| `/api/reboot` | GET | ESP32 Neustart |
| `/api/updates` | GET | Verfuegbare OTA-Updates `{available, games, firmware}` |
| `/api/updates/check` | POST | Update-Check erzwingen |
| `/api/update/start` | POST | OTA-Update starten |
| `/favicon.ico` | GET | 204 No Content |

---

## WebSocket-Protokoll

WebSocket laeuft auf Port **81** (separater Listener).
Alle Nachrichten sind JSON.

### ESP32 → Browser

```json
{"type": "nav",          "dir": "left|right|up|down"}
{"type": "action",       "kind": "puff|press"}
{"type": "puff_level",   "value": 0.0-1.0}
{"type": "wifi_status",  "mode": "station|ap", "ssid": "...", "ip": "..."}
{"type": "wifi_networks","networks": ["SSID1", "SSID2"]}
{"type": "config_values","deadzone": 150, "nav_threshold": 450, ...}
{"type": "config_saved", "ok": true}
{"type": "update_progress", "current": 2, "total": 5, "file": "chess.html.gz"}
{"type": "update_complete", "message": "..."}
```

### Browser → ESP32

```json
{"type": "wifi_config",    "ssid": "...", "password": "..."}
{"type": "wifi_scan"}
{"type": "config_preview", "deadzone": 200, ...}
{"type": "config_save",    "deadzone": 200, ...}
{"type": "config_reset"}
```

### In Spielen (Browser-seitig)

Spiele verbinden sich ueber `games/device-link.js` zu `ws://${location.hostname}:81` und reagieren auf
`nav`- und `action`-Events. Tastatur-Fallback funktioniert ohne WebSocket.

```
Joystick / Pfeiltasten:
  ◀▶  Spalte/Element wechseln
  ▲▼  Innerhalb einer Spalte navigieren

Pusten / Leertaste / Enter:
  Auswaehlen / Ablegen / Bestaetigen

Joystick-Button / Backspace:
  Rueckgaengig (Undo)

N = Neues Spiel  |  K = Kiosk-Modus  |  F = Vollbild
```

---

## OTA-Update-System

Beide Firmware-Varianten pruefen beim Boot `mundmaus.de/ota/manifest.json`
(Basic Auth). Das Portal zeigt verfuegbare Updates an — der User klickt
"Installieren".

- **Arduino**: ESP-IDF Dual-Partition + `markBootOk()` → automatischer Rollback
  bei fehlgeschlagenem Firmware-Update
- **MicroPython**: `.bak`-Dateien + `boot.py` Counter + Recovery-AP

### Deploy-Workflow

1. Code committen
2. `tools/update_manifest.py` — Versionen bumpen
3. Arduino-Firmware (nur wenn sie sich geaendert hat):
   `OTA_AUTH_B64=... pio run -e esp32` → `scp firmware.bin mbs:/srv/mundmaus/ota/`
4. `tools/deploy-ota.sh` — Manifest + Dateien auf mundmaus.de deployen
5. Das Geraet prueft beim naechsten Boot und danach alle 3 Stunden

**Basic-Auth-Zugangsdaten** liegen je Variante woanders: Arduino als Build-Flag
`OTA_AUTH_B64`, MicroPython in `ota_auth.py` (gitignored, nicht im Repo).

### Pruefstand vor jedem OTA

Ein ESP32 per USB am Entwicklungsrechner, nie das Geraet des Patienten.

- Host-Tests der Firmware (Updater, Config gegen Stubs): `firmware/arduino/test_host/run.sh`
- Lint, laeuft auch vor jedem Build mit geaenderten Quellen: `~/.platformio/penv/bin/python tools/lint_firmware.py [env]`
- Spiele ohne Geraet: `cd tests/e2e && npm run test:local`
- Alles gegen den Pruefstand: `ESP32_URL=http://<pruefstand> npm run test:device`
- Watchdog-Probe: Build `pio run -e esp32_testhooks -t upload`, dann
  `MUNDMAUS_TEST_HOOKS=1 ESP32_URL=... npx playwright test bench -g A3`
- Reconnect-Last: `MUNDMAUS_STRESS_MINUTES=30 ESP32_URL=... npx playwright test bench -g C1`.
  Vorher einen seriellen Logger starten, der den Port einmal oeffnet und mitschreibt:
  Das Oeffnen der Schnittstelle setzt den ESP32 zurueck, ein Haenger waere danach weg.

---

## Flash-Speicher

### ESP32-WROOM-32 (4 MB)

```
MicroPython Firmware:     ~1.5 MB
Python-Dateien (*.py):    ~0.05 MB
www/ Verzeichnis:         ~2.4 MB verfuegbar
```

### Arduino (4 MB, Dual-Partition)

```
App Partition 0:          ~1.5 MB
App Partition 1:          ~1.5 MB  (OTA Rollback)
LittleFS (www/):          ~1.0 MB
```

### ESP32-S3 N16R8 (16 MB)

~14 MB fuer www/ verfuegbar. Kein Platzproblem.

---

## Raspberry Pi Kiosk-Setup

Fuer den Dauerbetrieb am TV/Monitor: Raspberry Pi als dedizierter Browser-Client.

### 1. WiFi-Verbindung zum ESP32-Hotspot

```bash
# /etc/wpa_supplicant/wpa_supplicant.conf
network={
    ssid="MundMaus"
    psk="mundmaus1"
    priority=10
}
```

Oder: `sudo raspi-config` → System Options → Wireless LAN

### 2. Browser im Kiosk-Modus (Autostart)

```bash
#!/bin/bash
# /home/pi/start-mundmaus.sh

# Warte bis ESP32 erreichbar
echo "Warte auf MundMaus WiFi..."
while ! ping -c 1 -W 2 192.168.4.1 > /dev/null 2>&1; do
    sleep 2
done
echo "ESP32 erreichbar!"

# Cursor ausblenden
unclutter -idle 0 &

# Browser starten
chromium-browser \
    --kiosk \
    --no-first-run \
    --disable-infobars \
    --noerrdialogs \
    --disable-translate \
    --disable-features=TranslateUI \
    --check-for-update-interval=31536000 \
    http://192.168.4.1
```

```bash
chmod +x /home/pi/start-mundmaus.sh
echo "@/home/pi/start-mundmaus.sh" >> /etc/xdg/lxsession/LXDE-pi/autostart
```

### 3. Bildschirmschoner deaktivieren

```bash
sudo apt install xscreensaver
# GUI: Bildschirmschoner → Deaktivieren

# Oder via xset:
xset s off && xset -dpms && xset s noblank
```

### 4. Pakete

```bash
sudo apt install unclutter chromium-browser
```

---

## Troubleshooting

| Problem | Ursache | Loesung |
|---|---|---|
| ESP32 wird nicht erkannt | Nur Ladekabel (2 Adern) | **Datenkabel** verwenden (4 Adern) |
| Joystick driftet | Thermischer Drift KY-023 | Deadzone erhoehen (Settings ⚙) |
| Kein Puff erkannt | Schlauch undicht / Threshold zu hoch | Schlauch pruefen, Empfindlichkeit erhoehen (Settings ⚙) |
| WiFi "MundMaus" nicht sichtbar | ESP32 nicht gestartet | USB-Kabel pruefen, Serial Monitor |
| Spiele laden langsam | Erste Uebertragung (gzip) | Normal — danach schneller |
| WebSocket trennt sich | WiFi-Reichweite | ESP32 naeher an Client |
| ESP32-S3: ADC liest 0 | GPIO33-39 gibt es nicht | Firmware-Update mit Board-Erkennung |
| Display bleibt schwarz | SPI-Pins vertauscht | Verkabelung pruefen (A0/RST) |
| OTA-Update schlaegt fehl | Kein Internet im AP-Modus | ESP32 muss im Station-Modus sein |

---

## MicroPython-Version

Empfohlen: **v1.27.0+**

| Feature | ab Version | Nutzen |
|---|---|---|
| asyncio ausgereift | v1.25+ | Nicht-blockierende Hauptschleife |
| Auto-detect SPIRAM | v1.24+ | PSRAM auf S3 automatisch erkannt |
| ROMFS | v1.27 | HTML aus Flash ohne RAM-Kopie |
| Dynamic USB Device (S3) | v1.25+ | Zukuenftig: USB-HID Maus-Modus |

Download: [micropython.org/download/ESP32_GENERIC](https://micropython.org/download/ESP32_GENERIC/)

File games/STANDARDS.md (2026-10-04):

# MundMaus Spiele — Design-Standards

## Zielgruppe
Tetraplegie-Patient, steuert mit Joystick (4 Richtungen) + Pusten (1 Aktion).
Kein Keyboard, keine Maus, kein Touch.

## Eingabe
- Joystick: Navigation (hoch/runter/links/rechts)
- Puff: Aktion (auswaehlen, aufdecken, platzieren)
- Keyboard als Fallback fuer Entwicklung/Test (Pfeiltasten + Space/Enter)

## Visuelles Theme
- **Hintergrund**: Dark Navy #1a1a2e
- **Header**: Frosted glass (rgba, backdrop-filter blur), oben, zeigt Spielname + Status
- **Footer**: Hint-Leiste unten mit Steuerungshilfe (optional, in Kiosk-Mode versteckt)
- **Schrift**: System sans-serif, hell auf dunkel

## Cursor / Highlight
- **Farbe**: Gold #FFD700
- **Stil**: Goldener Rahmen (2-3px solid) UND goldener Hintergrund (rgba(255, 215, 0, 0.25))
- **Glow**: Optional box-shadow mit Gold-Ton
- **Konsistenz**: Identischer Stil in ALLEN Spielen

## Selection (ausgewaehltes Element)
- **Farbe**: Magenta #e040fb
- **Stil**: Magenta Rahmen + Hintergrund-Overlay (rgba(224, 64, 251, 0.25))

## Buttons (Neu, Zurueck, Hilfe)
- **Position**: RECHTS neben dem Spielfeld, vertikal gestapelt
- **Navigation**: Joystick rechts vom Spielfeld-Rand wechselt zu den Buttons
- **Cursor**: Gold-Highlight wenn Cursor auf Button
- **Pflicht-Buttons**: "Neu" (neues Spiel) in JEDEM Spiel. "Zurueck" (Undo) wo sinnvoll.
- **Disabled-Stil**: opacity 0.3 wenn nicht verfuegbar

## Spielfiguren (Schach)
- **Alle Figuren**: Ausgefuellte (filled) Unicode-Zeichen, NICHT Outline
- **Weiss**: CSS color weiss + dicker dunkler Stroke (text-shadow)
- **Schwarz**: CSS color schwarz/sehr dunkel + subtiler Stroke
- **Brett**: Mittlere Helligkeits-Toene (kein reines Weiss, kein tiefes Schwarz)

## Farben / Barrierefreiheit
- **WCAG AA Minimum**: 4.5:1 Kontrast fuer Text, 3:1 fuer grosse Elemente
- **CVD-safe**: Nie nur auf Farbe verlassen — immer zusaetzlich Form, Text oder Position
- **Triple-Encoding** (Memory): Symbol + Farbe + Text-Label

## WebSocket
- Eine Datei fuer alle Seiten: `device-link.js`, im `<head>` vor `conn-guard.js` geladen und mit
  `DeviceLink.start({ onMessage, onChange })` gestartet. Keine Seite oeffnet einen eigenen WebSocket
  (`tools/test-game.py` prueft das).
- Verbindung zu ws://{host}:81, Fallback ws://192.168.4.1:81 (ESP32 AP-Mode)
- Heartbeat `{"type":"hb"}` alle 2 s. 10 s ohne Nachricht: Punkt sofort grau, neuer Socket nach
  Backoff 3s -> 6s -> 12s -> 24s -> max 30s; antwortet HTTP wieder, sofort (conn-guard.js)
- Status-Dot: gruen = es kommen Daten, grau = getrennt (oben rechts)
- conn-guard.js laedt die Seite nur neu, wenn mehrere Sockets hintereinander oeffnen und nichts liefern,
  waehrend HTTP antwortet

## Kiosk-Mode (K)
- Taste K oder WS action "kiosk"
- Kombiniert Vollbild + vereinfachte Ansicht:
  1. Browser-Fullscreen (requestFullscreen API)
  2. Footer/Hints versteckt
  3. Idle-Screen nach 2min Inaktivitaet ("Pusten zum Starten")
- KEIN separater Vollbild-Modus (F) — alles ueber K

## Layout-Reihenfolge
1. Header (oben): Spielname links, Puff-Indicator mitte, Stats rechts, WS-Indikator rechts
2. Spielfeld (mitte): So gross wie moeglich
3. Buttons (rechts): Neben dem Spielfeld, nicht darunter
4. Footer (unten): Keyboard-Hints fuer Betreuer

## Ultrawide / Skalierung
- **body**: `max-width: 1920px; width: 100%` (nicht 100vw!)
- **Keine rohen vw-Einheiten**: Alle `vw`-Werte als `calc(X * var(--vw))` mit `--vw: min(1vw, 19.2px)` in `:root`
- **Grund**: Auf Ultrawide (3440px) wuerden vw-Werte den 1920px-Body sprengen
- **JS Inline-Styles**: Ebenfalls `calc(X * var(--vw))` verwenden, nicht `X + 'vw'`

## Footer-Hints (konsistent in ALLEN Spielen)
Format mit kbd-Tags fuer Tastatur-Shortcuts:
- `←↑→↓` Navigieren
- `Leertaste` [spielspezifische Aktion]
- `N` Neues Spiel
- `K` Kiosk
- Spielspezifisch: `U` Rueckgaengig (Chess), `F` Vollbild etc.
Hinweise dienen Betreuern (wechselnde Pfleger, keine Schulung).
Der Nutzer selbst braucht nur Joystick + Pusten.

## Puff-Indicator
- **Position**: Im Header, zwischen Titel und Stats
- **Aufbau**: Emoji (💨) + schmaler Balken (8vw breit, 0.6vh hoch)
- **Balken**: Gold-Farbe (--highlight/--cursor-color), Breite = puff_level (0-100%)
- **Pflicht**: JEDES Spiel muss den Puff-Indicator im Header haben
- **JS**: WebSocket `puff_level` Event setzt `puff-bar` Breite
- **NICHT** als fixed-Element unten positionieren (kollidiert mit Footer)

## Header-Stats
- Stat-Werte in Gold (#FFD700), Labels in heller Schrift
- Tabular-Nums fuer Zahlen (kein Springen)
- Konsistentes Format: "Label: Wert"

## WebSocket-Verbindungsindikator
- Position: oben rechts, fixed
- Gruener Punkt = es kommen Daten, grauer Punkt = getrennt
- Identisch in ALLEN Spielen (gleiche CSS-Klasse, gleiche Position)

## Betreuer-Hinweise
Wechselnde Pfleger muessen die Spiele ohne Schulung bedienen koennen:
- Footer zeigt alle Tastatur-Shortcuts (Pfeiltasten, Leertaste, N, K)
- Buttons (Neu, Zurueck) sind gross und beschriftet
- Kiosk-Mode (K) vereinfacht die Ansicht fuer den Nutzer
- WiFi-Setup ueber 📶 Symbol im Header (Solitaire) erreichbar

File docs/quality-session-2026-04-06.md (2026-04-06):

# MundMaus Quality Session — 2026-04-06

## Kontext
Assistive Gaming Controller fuer einen tetraplegischen Patienten. ESP32 + Mundjoystick + Drucksensor. 6 Browser-Spiele auf dem Fernseher. Zero Defects Anforderung — die Spiele sind die einzige Abwechslung.

---

## Neue Features

### Charge-Navigation (alle 6 Spiele)
- **Unsichtbarer Cooldown ersetzt durch sichtbare Ladeanzeige**: SVG-Rahmen zeichnet sich im Uhrzeigersinn um das Zielfeld
- **Joystick-Intensitaet**: analog 0.0–1.0, staerker = schneller laden
- **Keyboard Dual-Mode**: "J" toggelt zwischen Direkt (Pfleger, sofort) und Joystick-Sim (Patient-Test, Charge)
- **NAV_COOLDOWN_MS**: Konfigurierbarer Default 1000ms, Range 50–3000ms, live preview in Settings

### Muehle (neues Spiel)
- 24-Position Board mit 3 AI-Schwierigkeitsgraden (Minimax + Alpha-Beta)
- Multiplayer-Toggle ("M"), Setzphase + Zugphase, Mill-Erkennung mit Glow
- Grosse Spielsteine (r=5.0) mit Highlight-Layer ueber den Steinen

### Multiplayer-Modus
- Vier gewinnt + Muehle: "M" toggelt zwischen KI und Pfleger-Gegner
- Gleiche Eingabeformen fuer beide Spieler

### Firmware v3.9
- Joystick-Axis-Hysterese (1.4x Faktor gegen Diagonal-Flipping)
- Stabilitaetsbasierter Drift-Guard (auto-rekalibriert nach 30s stabiler Drift)
- WiFi-Reconnect in Background-Task (kein WDT-Crash mehr)
- OTA Rollback-Schutz (pending_fw in NVS, erst bei erfolgreichem Boot promoted)
- Async WiFi-Scan (blockiert AsyncTCP nicht mehr)

---

## Bugs gefixt (nach Kategorie)

### Firmware (8 Bugs)
| Bug | Root Cause | Fix |
|-----|---|-----|
| Joystick friert ein | ADC-Rauschen flippt X/Y 50x/s bei Diagonal | Axis-Hysterese 1.4x |
| Auto-Rekal waehrend Nutzung | isIdle() Gap (DEADZONE*2 vs NAV_THRESHOLD) | isIdle() auf DEADZONE gesenkt |
| Joystick driftet | Center verschiebt sich ueber Zeit | Stabilitaets-Drift-Guard (30s) |
| WDT-Crash bei WiFi-Reconnect | connectStation() blockiert 49s, WDT=30s | Background-Task |
| Truncated OTA silently installiert | Kein Size-Check nach Download | contentLen + write Validierung |
| _updateResult Race Condition | Background-Task vs AsyncTCP | FreeRTOS Mutex |
| Stale Firmware nach Rollback | Version in NVS vor Boot gespeichert | pending_fw Pattern |
| Config-Werte ungeranged | Korrupte NVS-Werte nicht geklemmt | constrain() in load() |

### Games — Logik (9 Bugs)
| Bug | Spiel | Root Cause | Fix |
|-----|---|---|-----|
| Karte nicht ablegbar | Solitaire | isSamePos() vergleicht stale cardIdx | Nur Zone+Spalte |
| Karte nicht ablegbar | Freecell | Gleicher isSamePos Bug | Nur Zone+Spalte |
| Figur nicht abwaehlbar | Chess | Re-select statt deselect bei gleicher Pos | Same-pos = deselect |
| AI crasht bei Neu | Muehle/Chess/VG | setTimeout nicht cancelable | Handle + re-check guards |
| autoComplete stackt | Solitaire | setInterval lokal, kein Guard | Globaler Handle + reentry |
| computeTarget falsch | Solitaire | navZone statt z Variable | Variable gefixt |
| Win-Overlay bleibt | Solitaire+Freecell | message.className nicht gecleart | Clear in initGame() |
| WS-Reconnect stackt | Solitaire+Freecell | Kein Timer-Dedup | Handle + clearTimeout |
| Memo stale Callbacks | Memo | setTimeout captures stale refs | Generation-Counter |

### Games — Visuell (7 Fixes)
| Problem | Spiel | Fix |
|---|---|-----|
| Karten gequetscht (Wert geht in Symbol) | Solitaire+Freecell | Kartenhöhe 13.3→14.5vw, Center-Font 4.5→3.5vw, Padding |
| Gestapelte Karten verschmelzen | Solitaire+Freecell | Dynamischer FUO (3.8vw normal, 1.2vw minimum bei langen Stapeln) |
| Karten laufen aus Viewport | Solitaire+Freecell | FUO basiert auf tatsaechlicher Viewport-Hoehe |
| Foundation-Slots unsichtbar | Solitaire+Freecell | Border 0.15→0.3, Label 0.2→0.4, Font 2.5→3.5vw |
| Header blau statt schwarz | Solitaire+Freecell | rgba(15,52,96) → rgba(0,0,0,0.7) |
| Footer blau statt schwarz | Solitaire+Freecell | Gleiches Fix wie Header |
| Action-Buttons fast unsichtbar | Alle 6 | Border 0.12→0.25, Background 0.06→0.1 |

### Konsistenz (6 Fixes)
| Problem | Fix |
|---|-----|
| Footer Sprache Mix (DE/EN) | Icon-Sprache ueberall (↻ ↩ 💡 ⌨ 👥 📺 🏠) |
| KB-Mode nur in 2 Spielen | Alle 6 Spiele haben J-Taste + ⌨ Indicator |
| Charge-Nav nur in 2 Spielen | Alle 6 Spiele haben Charge-Mechanik |
| navigate() cancelt Charge nicht | Alle 6 Spiele: cancelCharge() in navigate() |
| initGame() cancelt Charge nicht | Alle 6 Spiele: cancelCharge() in initGame() |
| Puff-Icon kaum sichtbar | Alle 6 Spiele: 0.25→0.5 Opacity |

---

## Quality Gates (automatisiert)

### Firmware
- **cppcheck + clang-tidy**: `--fail-on-defect=low`, 8 Check-Kategorien
- **Pre-Build Lint**: Automatisch vor jedem `pio run`, gecacht via `.lint_passed` Marker
- **Null-Guards**: Alle Pointer im sensorTask geprueft (joystick, server, puffSensor)
- **Volatile Config**: Cross-Core Globals als `volatile int`
- **Atomic Flags**: `std::atomic<bool>` fuer TOCTOU-sichere Scan/Update Guards
- **Single ADC Read**: `sampleRaw()` einmal pro Iteration, alle Methoden nutzen Cache
- **Safe Broadcast**: `_broadcastText()` via makeBuffer + shared_ptr

### Games
- **cancelCharge()** in navigate() und initGame() — verhindert stale Charge State
- **AI Timer cancelable** — clearTimeout + re-check Guards in Callback
- **autoComplete guarded** — globaler Handle + reentry Prevention
- **WS-Reconnect deduped** — Timer Handle + clearTimeout
- **Generation Counter** (Memo) — invalidiert stale setTimeout Callbacks
- **Dynamic Card Stacking** — FUO skaliert mit Viewport-Hoehe

### OTA
- **Fresh-Flash Marker** (`.ota_marker`) — erkennt USB-Flash, cleared stale NVS
- **Firmware Version Seeding** — MUNDMAUS_FW_VERSION Build-Flag
- **Truncation Validation** — contentLen + write Return-Value Check
- **Rollback Protection** — pending_fw in NVS, nur bei erfolgreichem Boot promoted

---

## Test-Methodologie

### Playwright Deep-Tests (alle 6 Spiele)
1. **Win-State erzwingen** → Overlay erscheint → neues Spiel → Overlay weg, State clean
2. **Deselect-Zyklus** → Karte auswaehlen → wegnavigieren → zurueck → gleiche Position = Abwahl
3. **Undo-Kette** → Zuege machen → undo bis leer → kein Crash
4. **Rapid New-Game** → 10x schnell hintereinander → kein State-Leak
5. **AI-Cancel** → Zug machen → waehrend AI denkt "N" → Menu erscheint, kein Crash
6. **Multiplayer-Toggle** → M druecken → beide Seiten spielbar
7. **Zone-Navigation** → Alle Uebergaenge (Tableau↔Top, Board↔Buttons)
8. **Volle Spalte** (Vier gewinnt) → Drop auf volle Spalte → abgelehnt

### Visuelle Tests (Playwright Screenshots)
1. **Normal-Spiel** bei 1920x1080 → Proportionen, Lesbarkeit
2. **Max-Stack** (13 face-up Solitaire) → Dynamischer FUO → alle Karten + Cursor sichtbar
3. **Ultrawide** (3440x1440) → max-width Cap funktioniert
4. **Opacity-Audit** → Alle rgba() < 0.3 auf Lesbarkeit geprueft

### Firmware-Tests
1. **Lint**: cppcheck + clang-tidy bei jedem Build
2. **Boot-Verify**: Serial Monitor "Bereit." + Heap-Check
3. **API-Test**: `/api/settings`, `/api/updates` korrekte JSON-Antworten
4. **WebSocket**: Connect + wifi_status Message empfangen
5. **OTA-Verify**: Manifest + MD5 Server vs Lokal
6. **WDT**: WiFi-Reconnect ueberlebt 30s Timeout (Background-Task)

---

## Versions-Stand nach Session

| Datei | Version | Aenderungen |
|---|---|---|
| firmware.bin | v40 (3.9) | Hysterese, Drift-Guard, volatile, atomic, safe broadcast |
| solitaire | v27 | Charge-Nav, Deselect, autoComplete, dynamic FUO, Slot-Visibility |
| freecell | v19 | Charge-Nav, Deselect, dynamic FUO, Slot-Visibility, WS-Dedup |
| chess | v15 | Charge-Nav, Deselect, AI-Cancel, Visibility |
| memo | v14 | Charge-Nav, Gen-Counter, Visibility |
| muehle | v4 | Neues Spiel, grosse Steine, Board-Border, Visibility |
| vier-gewinnt | v13 | Multiplayer, Charge-Nav, checkWinAt, AI-Cancel, Visibility |
| settings | v5 | NAV_COOLDOWN_MS Anzeige (ms pro Sprung) |

## Bekannte Defekte: 0

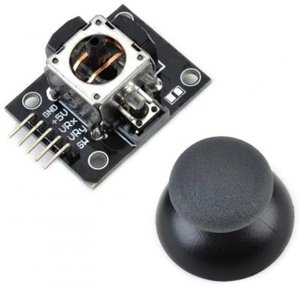
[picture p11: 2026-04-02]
website/img/hw/joystick.jpg

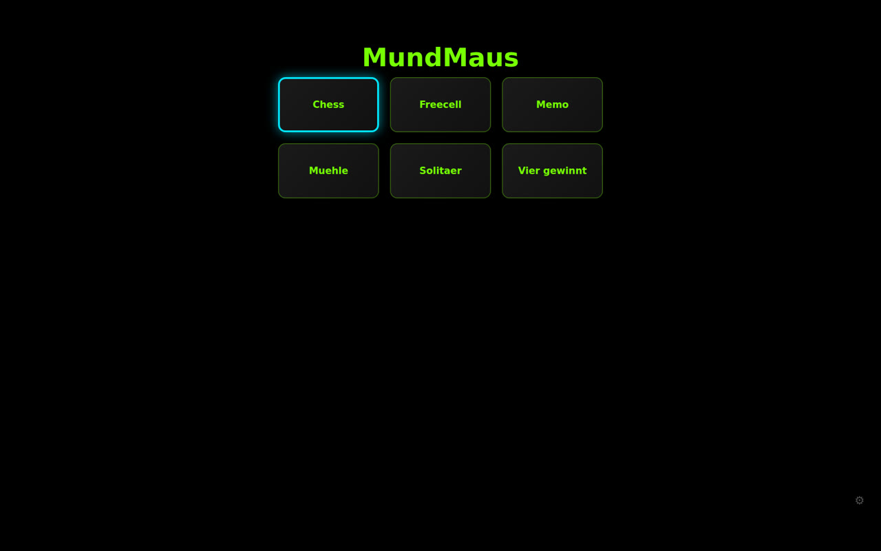
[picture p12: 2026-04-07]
website/img/portal.jpg

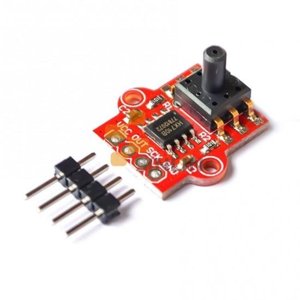
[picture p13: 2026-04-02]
website/img/hw/pressure.jpg

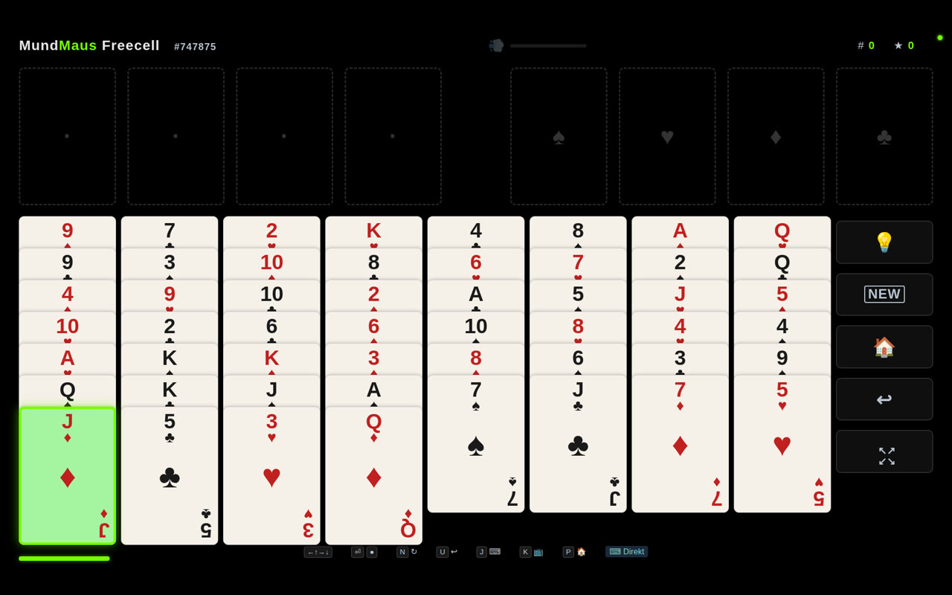
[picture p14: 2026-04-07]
website/img/freecell.jpg

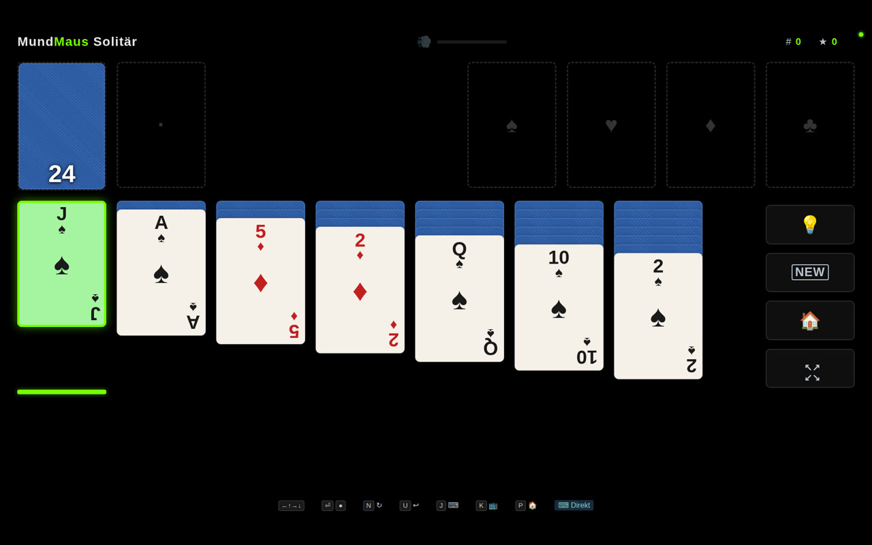
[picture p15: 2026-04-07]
website/img/solitaire.jpg

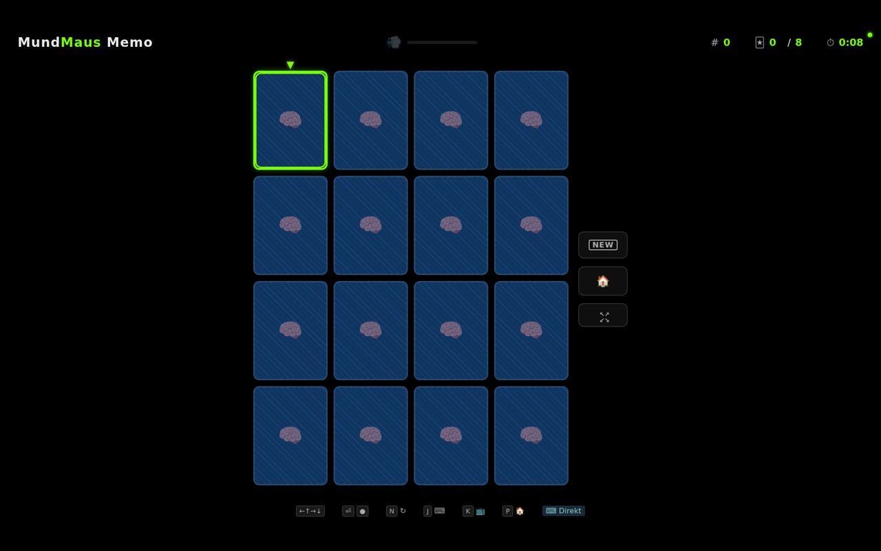
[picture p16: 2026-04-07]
website/img/memo.jpg

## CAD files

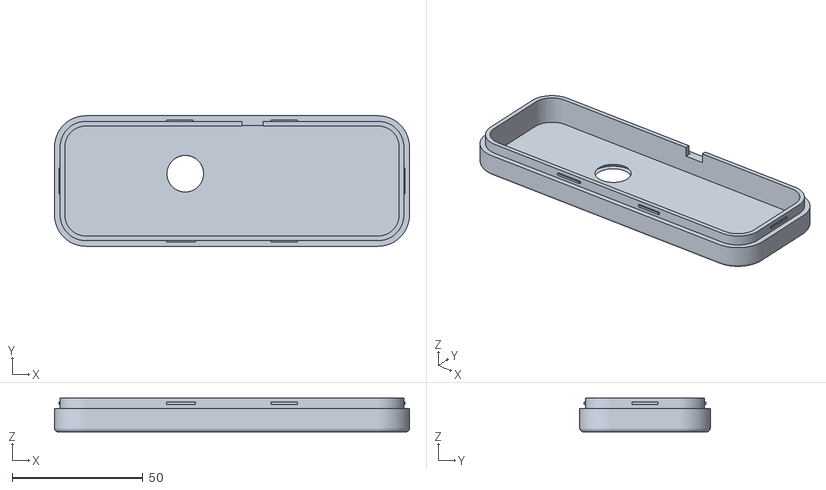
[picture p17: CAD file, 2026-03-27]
enclosure/mundmaus_v55_lid.stl
136.0 x 50.0 x 13.0

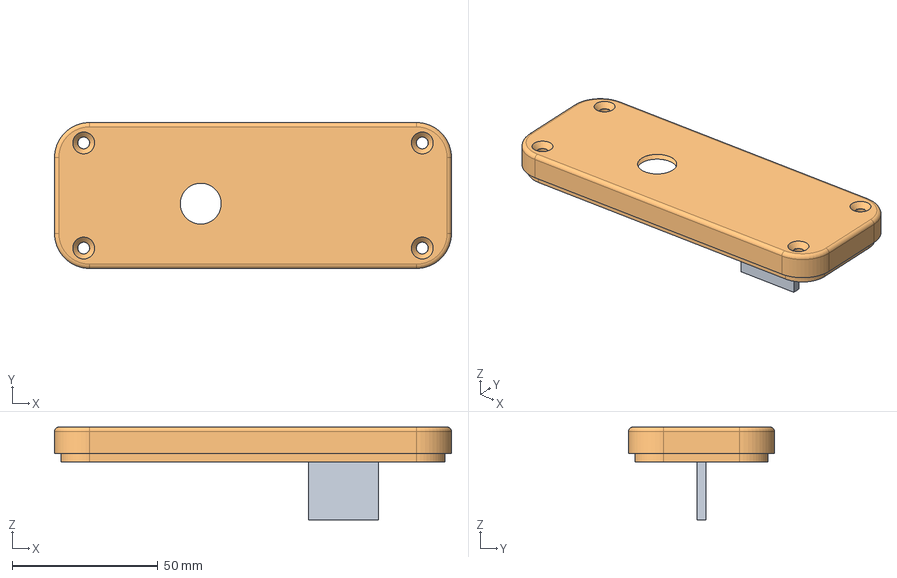
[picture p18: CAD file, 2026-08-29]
enclosure/output_v58/mundmaus_v58_lid.step
136.0 x 50.0 x 31.8 mm

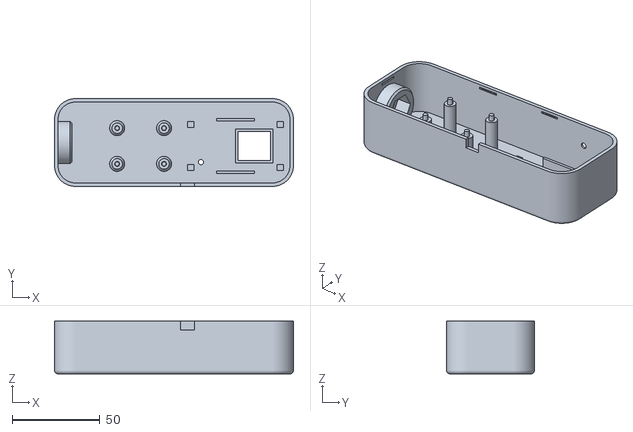
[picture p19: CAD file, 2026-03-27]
enclosure/mundmaus_v55_base.stl
136.0 x 50.0 x 30.0

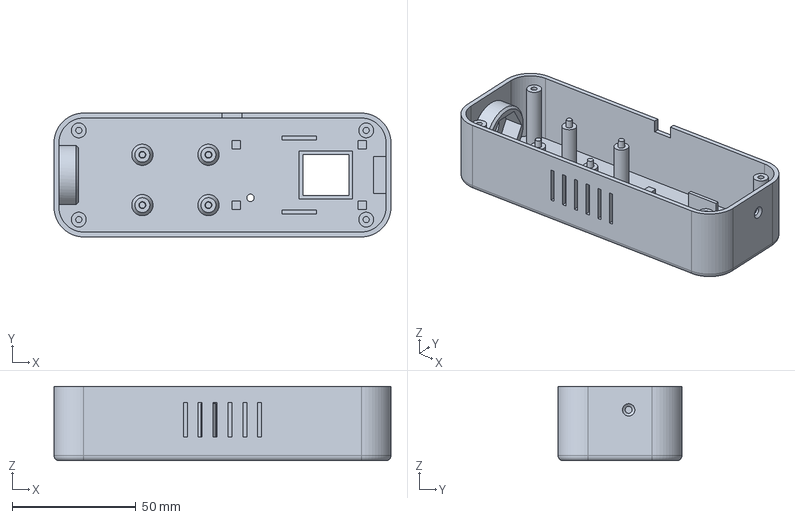
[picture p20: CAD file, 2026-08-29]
enclosure/output_v58/mundmaus_v58_base.step
136.0 x 50.0 x 30.0 mm

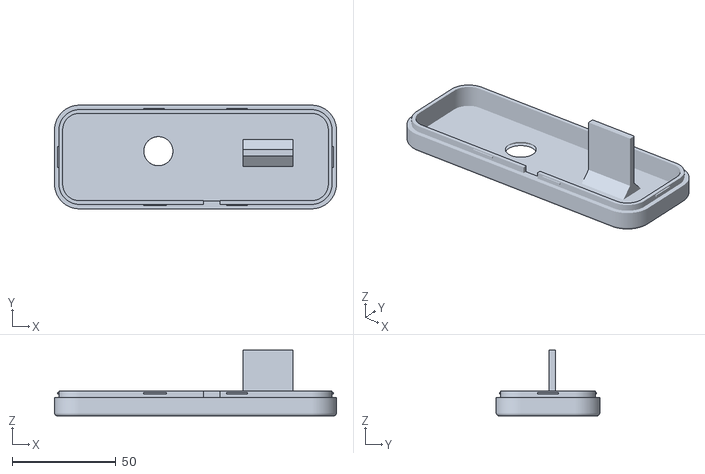
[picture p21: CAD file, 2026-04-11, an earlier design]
enclosure/output/mundmaus_v57_lid.stl
136.0 x 50.0 x 31.8

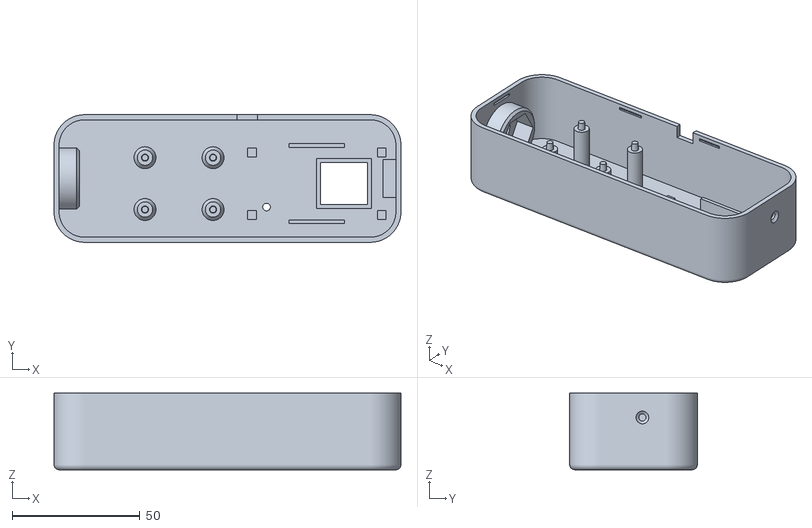
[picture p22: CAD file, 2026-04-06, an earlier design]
enclosure/output/mundmaus_v57_base.stl
136.0 x 50.0 x 30.0

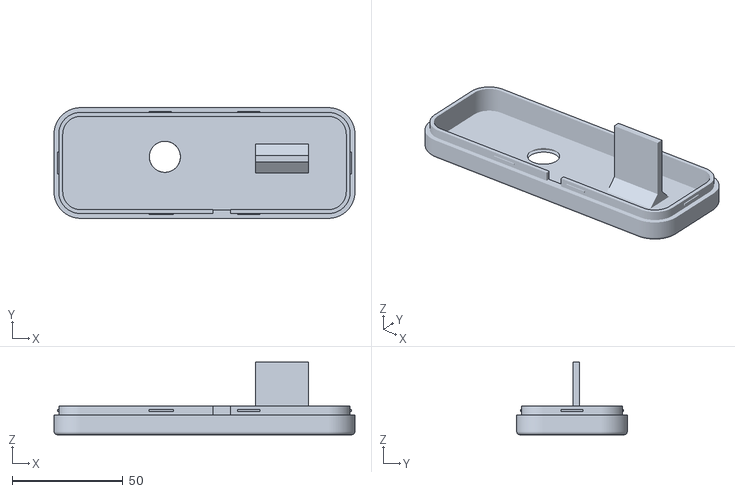
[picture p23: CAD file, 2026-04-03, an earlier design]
enclosure/output/mundmaus_v55_lid.stl
136.0 x 50.0 x 32.8

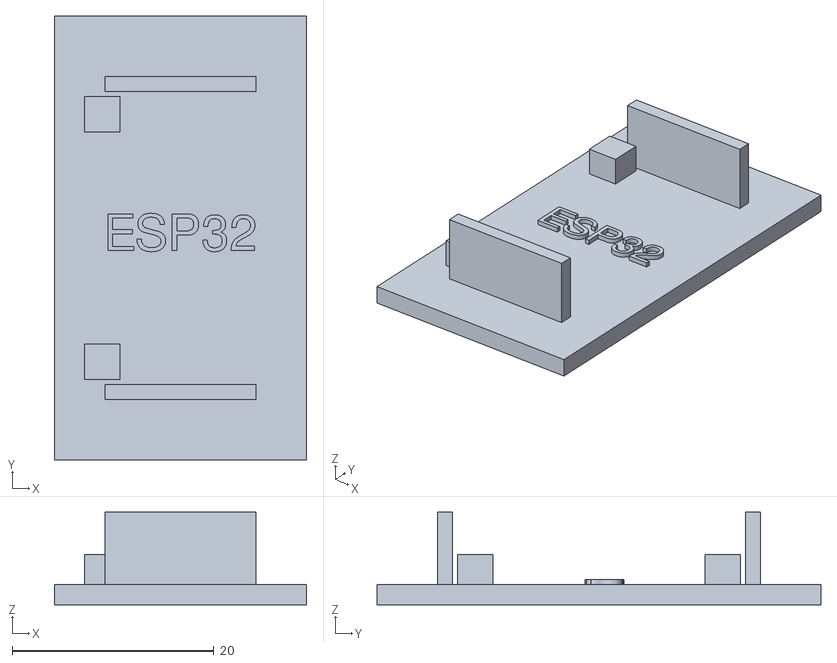
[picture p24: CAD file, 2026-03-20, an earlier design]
enclosure/output/mundmaus_fit_test_esp.stl
25.0 x 44.0 x 9.20

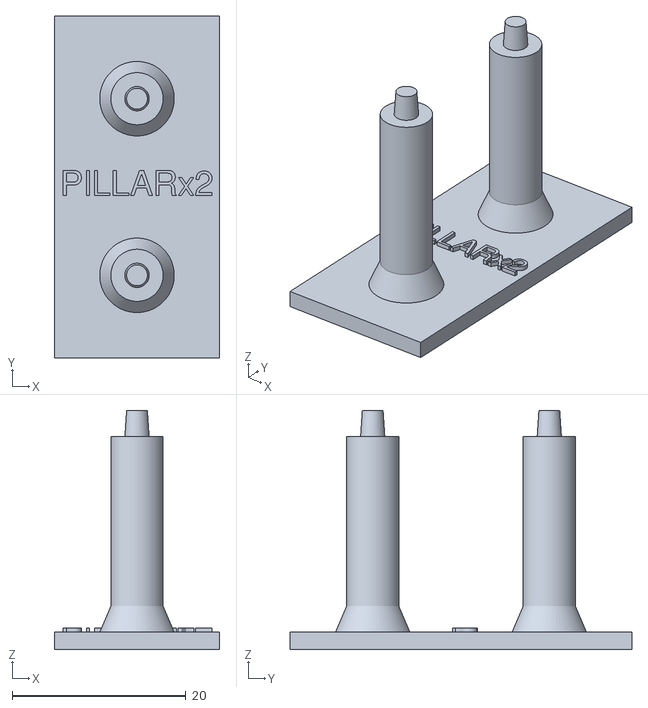
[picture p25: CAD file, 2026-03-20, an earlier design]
enclosure/output/mundmaus_fit_test_pillar.stl
19.0 x 39.3 x 27.5

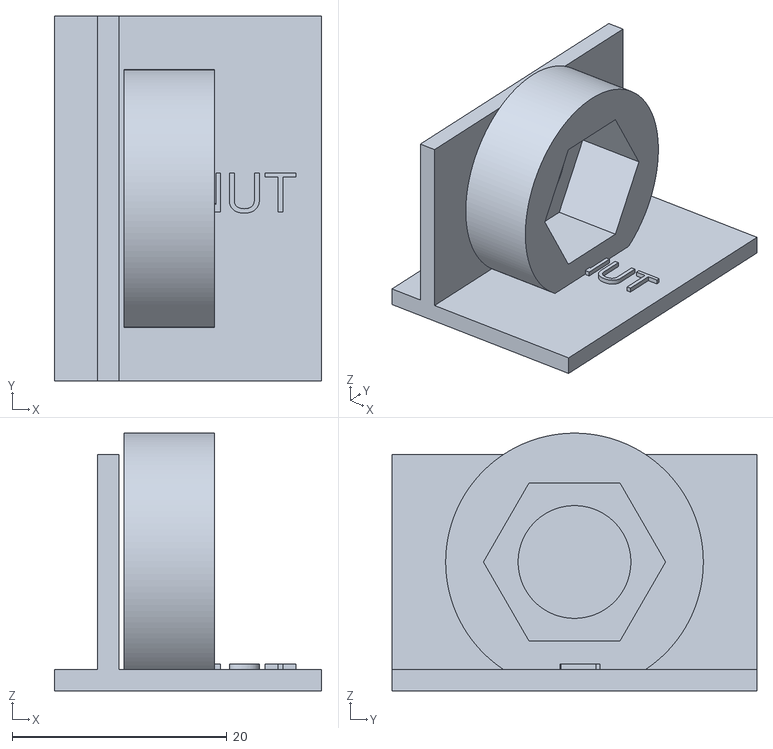
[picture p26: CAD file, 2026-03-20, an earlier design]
enclosure/output/mundmaus_fit_test_nut.stl
24.9 x 34.0 x 24.0

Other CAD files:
enclosure/output/mundmaus_v56_lid.stl
enclosure/output/mundmaus_v55_base.stl
enclosure/output_v58/mundmaus_v58_base.stl
enclosure/output_v58/mundmaus_v58_lid.stl

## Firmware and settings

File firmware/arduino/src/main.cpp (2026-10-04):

// main.cpp -- MundMaus ESP32 Firmware (Arduino)
// Phases 1-7: Boot + WiFi + HTTP/WS + Sensors + LittleFS + Config + OTA

#include <Arduino.h>
#include <WiFi.h>
#include <esp_task_wdt.h>
#include <esp_system.h>
#include <atomic>

#include "config.h"
#include "wifi_manager.h"
#include "web_server.h"
#include "sensors.h"
#include "updater.h"
#include "wifi_log.h"

// Globals (must outlive setup)
static WiFiManager wifi;
static MundMausServer* server = nullptr;
static CalibratedJoystick* joystick = nullptr;
static PuffSensor* puffSensor = nullptr;

// Heartbeat timestamp for WDT (written by sensor task, read by loop)
static volatile unsigned long sensorHeartbeat = 0;

// Core-0 liveness heartbeat. A blocked or deadlocked AsyncTCP handler is caught
// by the task watchdog AsyncTCP subscribes its own task to (library default
// CONFIG_ASYNC_TCP_USE_WDT=1; verified on the bench, test A3 in
// tests/e2e/bench.spec.ts). This covers the other case: Core 0 not scheduling
// at all, because something there spins. A tiny 1 Hz task pinned to Core 0
// bumps this; loop() stops feeding the WDT once it goes stale, exactly like the
// sensor heartbeat. A low-priority 1 Hz task only fails to run for 30 s if
// Core 0 genuinely cannot schedule it, so this does not false-trigger during
// normal (millisecond) AsyncTCP activity.
static volatile unsigned long core0Heartbeat = 0;

static void core0HeartbeatTask(void*) {
    for (;;) {
        core0Heartbeat = millis();
        vTaskDelay(pdMS_TO_TICKS(1000));
    }
}

// Timestamp of the last station-recovery probe while in AP fallback. File scope
// so the reconnect task can stamp it the moment the fallback engages: otherwise
// it stayed 0, the "> 5 min" test was already true when the fallback happened
// (t ~ 372 s), and the very first thing a carer got after the hotspot appeared
// was another connect attempt cycling the radio out from under them.
static std::atomic<unsigned long> lastApRetry{0};

// Sensor health snapshot for the OTA manifest poll. The OTA server's access
// log records the query string so we can diagnose patient devices remotely
// (no usage data — just calibration + idle sensor state).
//
// Thread-safety: rawX/rawY are written by the sensor task on Core 1 at 50 Hz;
// this function is called from the OTA boot/periodic tasks (Core 0 or 1).
// Individual int reads are atomic on Xtensa (aligned 32-bit), but the four
// reads here are not a consistent snapshot. That is acceptable: telemetry is
// for offline diagnostics, not control flow — a torn pair just shows a
// transient state that the next 3h poll will smooth out.
static String _otaTelemetry() {
    String t;
    if (joystick) {
        t  = "jx=" + String(joystick->rawX);
        t += "&jy=" + String(joystick->rawY);
        t += "&cx=" + String(joystick->centerX);
        t += "&cy=" + String(joystick->centerY);
    }
    if (t.length()) t += "&";
    if (puffSensor) {
        // Percent, not the bare 0.0-1.0 float: (int)getLevel() truncated every
        // reading below 1.0 to "0", so a sensor latched at 25 % looked exactly
        // like a healthy idle one. That is why the patient's dead click was
        // invisible here and only surfaced when he reported it.
        // baseline/raw/rebases make a stuck baseline diagnosable remotely.
        t += "p="    + String((int)(puffSensor->getLevel() * 100.0f));
        t += "&pb="  + String((int)puffSensor->baseline);
        t += "&pr="  + String((int)puffSensor->lastRaw());
        t += "&prb=" + String((unsigned)puffSensor->rebaseCount());
    } else {
        t += "p=na";
    }
    return t;
}

// ============================================================
// SENSOR TASK (FreeRTOS, Core 1, 50Hz)
// ============================================================

static void sensorTask(void* param) {
    (void)param;

    unsigned long lastPuffSend = 0;

    for (;;) {
        unsigned long now = millis();
        const char* holdState = nullptr;

        // Sample ADC once per iteration -- all joystick methods use cached values
        if (joystick) joystick->sampleRaw();

        // -- I3: Handle calibrate request from WS handler (non-blocking) --
        if (server && server->calibrateRequested) {
            server->calibrateRequested = false;
            Serial.println("  Calibrating (from WS request)...");

            if (joystick) {
                joystick->calibrate();
            }
            if (puffSensor) {
                puffSensor->calibrateBaseline();
            }

            // C1: Send calibrate_done with correct JSON keys (match MicroPython)
            SensorEvent ev;
            ev.type = SensorEvent::CALIBRATE_DONE;
            ev.value = 0;
            ev.intVal  = joystick ? joystick->centerX : 0;
            ev.intVal2 = joystick ? joystick->centerY : 0;
            ev.intVal3 = puffSensor ? puffSensor->baseline : 0;
            xQueueSend(server->sensorQueue(), &ev, 0);
        }

        // -- Joystick navigation --
        // Defensive null-check: server is set in setup() before this task is
        // spawned, but guarding here means future restructuring (e.g. starting
        // the sensor task earlier for WDT keep-alive) cannot silently crash.
        if (joystick && server) {
            const char* nav = joystick->pollNavigation();
            if (nav) {
                server->sendNav(nav);
            }

            // -- Joystick button --
            if (joystick->pollButton()) {
                server->sendAction("press");
            }
        }

        // -- Continuous nav state for charge-based games --
        if (joystick) {
            static bool wasNavigating = false;
            static unsigned long releaseStart = 0;
            float holdIntensity = 0.0f;
            holdState = joystick->getState(holdIntensity);
            if (holdState) {
                static unsigned long lastHoldSend = 0;
                releaseStart = 0;  // cancel any pending release
                // Throttle nav_hold to ~10Hz (every 100ms)
                if ((now - lastHoldSend) >= 100) {
                    server->sendNavHold(holdState, holdIntensity);
                    lastHoldSend = now;
                }
                wasNavigating = true;
            } else if (wasNavigating) {
                // 100ms release debounce -- prevents brief deadzone crossings
                // (joystick jitter) from firing premature nav_release events
                if (releaseStart == 0) {
                    releaseStart = now;
                } else if ((now - releaseStart) > 50) {
                    server->sendNavRelease();
                    wasNavigating = false;
                    releaseStart = 0;
                }
            }
        }

        // -- Debug joystick stream (5Hz, toggled via WS "debug_joy") --
        if (joystick && server && server->debugJoystick) {
            static unsigned long lastDebug = 0;
            if ((now - lastDebug) >= 200) {
                lastDebug = now;
                int dx = joystick->rawX - joystick->centerX;
                int dy = joystick->rawY - joystick->centerY;
                SensorEvent ev;
                ev.type = SensorEvent::DEBUG_JOYSTICK;
                ev.intVal  = joystick->rawX;
                ev.intVal2 = joystick->rawY;
                ev.intVal3 = dx;
                // Pack dy, direction, axis into data string
                snprintf(ev.data, sizeof(ev.data), "%d,%s,%c",
                    dy,
                    holdState ? holdState : "none",
                    joystick->lastAxis() ? joystick->lastAxis() : '-');
                xQueueSend(server->sensorQueue(), &ev, 0);
            }
        }

        // -- Puff sensor --
        if (puffSensor) {
            puffSensor->poll();

            // Broadcast puff level periodically
            if ((now - lastPuffSend) > (unsigned long)Config::DEFAULT_PUFF_SEND_INTERVAL_MS) {
                float level = puffSensor->getLevel();
                static bool wasActive = false;
                if (level > 0.02f) {
                    server->sendPuffLevel(level);
                    wasActive = true;
                } else if (wasActive) {
                    server->sendPuffLevel(0.0f);  // reset bar to zero
                    wasActive = false;
                }
                lastPuffSend = now;
            }

            // Detect puff event
            if (puffSensor->detectPuff()) {
                server->sendAction("puff");
            }
        }

        // Update heartbeat for WDT check in loop()
        sensorHeartbeat = now;

        vTaskDelay(pdMS_TO_TICKS(Config::SENSOR_POLL_MS));
    }
}

// ============================================================
// SETUP
// ============================================================

// cppcheck-suppress unusedFunction -- the Arduino core calls it (cores/esp32/main.cpp, core 3.3.7)
void setup() {
    Serial.begin(115200);
    while (!Serial && millis() < 2000) { delay(10); }

    // Hardware watchdog (30s timeout)
    const esp_task_wdt_config_t wdtCfg = {
        .timeout_ms       = 30000,
        .idle_core_mask   = 0,       // don't watch idle tasks
        .trigger_panic    = true,
    };
    esp_task_wdt_reconfigure(&wdtCfg);
    esp_task_wdt_add(nullptr);

    // Boot-crash-loop guard — FIRST, before any crash-prone init. If a freshly
    // OTA'd image keeps crashing after setup() (where markBootOk cancels the
    // bootloader rollback), this rolls back to the last known-good partition so
    // the device self-heals instead of needing an on-site re-flash.
    Updater::checkBootCrashLoop();

    // Load saved settings from NVS
    Config::load();

    // WiFi diagnostic log: persistent boot counter + LittleFS rotating log.
    // Must come BEFORE wifi.startup() so connectStation() can log events.
    WifiLog::init();
    WifiLog::log(String("event=boot version=") + Config::VERSION +
                 " reset_reason=" + (int)esp_reset_reason());

    // Banner
    Serial.println();
    Serial.println("==========================================");
    Serial.printf( "  MUNDMAUS v%s (boot #%u)\n", Config::VERSION, (unsigned)WifiLog::bootCount());
    Serial.printf( "  Board: %s\n", BOARD_NAME);
    Serial.println("==========================================");

    // WiFi — serial provisioning if no credentials saved
    Serial.println("\n[Netzwerk]");
    if (!wifi.loadCredentials()) {
        Serial.println("  Keine WLAN-Daten. Serial-Provisioning (5s):");
        Serial.println("  Format: SSID:PASSWORD");
        // Rollover-safe form (millis()-start), though at boot millis() is tiny
        // and the additive form was harmless here — keeps the codebase free of
        // the unsafe `millis() + x` pattern.
        unsigned long start = millis();
        while (millis() - start < 5000) {
            if (Serial.available()) {
                String line = Serial.readStringUntil('\n');
                line.trim();
                int sep = line.indexOf(':');
                if (sep > 0) {
                    String ssid = line.substring(0, sep);
                    String pass = line.substring(sep + 1);
                    if (wifi.saveCredentials(ssid, pass)) {
                        Serial.printf("  WiFi gespeichert: %s\n", ssid.c_str());
                    } else {
                        Serial.println("  FEHLER: WiFi-Speichern fehlgeschlagen (NVS)");
                    }
                    break;
                }
            }
            delay(50);
            esp_task_wdt_reset();
        }
    }
    auto [ip, wifiMode] = wifi.startup();

    Serial.println();
    Serial.println("  ======================================");
    if (wifiMode == "ap") {
        Serial.printf("  HOTSPOT: %s / %s\n", Config::AP_SSID, Config::AP_PASS);
    } else {
        Serial.printf("  WLAN: %s\n", wifi.ssid.c_str());
    }
    Serial.printf("  IP: %s\n", ip.c_str());
    Serial.printf("  http://%s\n", ip.c_str());
    Serial.println("  ======================================");

    // Feed WDT after WiFi (may have taken a few seconds)
    esp_task_wdt_reset();

    // -- Sensors --
    Serial.println("\n[Sensoren]");

    // Joystick (always initialized)
    joystick = new CalibratedJoystick(PIN_VRX, PIN_VRY, PIN_SW);
    bool joystickOk = (joystick->centerX > 200 && joystick->centerX < 3900 &&
                       joystick->centerY > 200 && joystick->centerY < 3900);
    if (joystickOk) {
        Serial.println("  Joystick: OK");
    } else {
        Serial.printf("  Joystick: WARNUNG Center=(%d,%d) ausserhalb 200-3900\n",
                      joystick->centerX, joystick->centerY);
    }

    esp_task_wdt_reset();

    // Puff sensor (may fail if not connected)
    puffSensor = new PuffSensor(PIN_PUFF_DATA, PIN_PUFF_CLK);
    bool puffOk = (puffSensor->baseline != 0);
    if (puffOk) {
        Serial.println("  Drucksensor: OK");
    } else {
        Serial.println("  Drucksensor: nicht erkannt (Baseline=0)");
        delete puffSensor;
        puffSensor = nullptr;
    }

    esp_task_wdt_reset();

    // HTTP + WebSocket server
    Serial.println("\n[Server]");
    server = new MundMausServer(wifi);
    server->hwStatus.joystick = joystickOk;
    server->hwStatus.puff     = puffOk;
    server->setSensors(joystick, puffSensor);
    server->start();

    // Start sensor task on Core 1, priority 2, 8KB stack (I7: increased from 4KB)
    sensorHeartbeat = millis();
    xTaskCreatePinnedToCore(
        sensorTask,
        "sensors",
        8192,
        nullptr,
        2,              // priority (above loop's 1)
        nullptr,
        1               // Core 1 (WiFi/AsyncTCP on Core 0)
    );
    Serial.println("\n[Sensor-Task] gestartet (Core 1, 50Hz)");
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
void loop() {
    // N6: Only feed WDT if the sensor task is alive...
    if (millis() - sensorHeartbeat > 30000) {
        Serial.println("  WDT: sensor task hung, NOT feeding");
        return;  // Let WDT reset the device
    }
    // ...and Core 0 (AsyncTCP + WiFi) is alive. A wedged Core 0 kills HTTP+WS —
    // the patient's whole input path — while this Core-1 loop keeps running, so
    // without this the WDT would never fire. core0Heartbeat==0 means the watch
    // task could not start; skip the gate then rather than reboot-loop.
    if (core0Heartbeat != 0 && millis() - core0Heartbeat > 30000) {
        Serial.println("  WDT: Core 0 (AsyncTCP) haengt, NOT feeding");
        return;  // Let WDT reset the device
    }
    esp_task_wdt_reset();

    if (server) {
        // I1: Process sensor events on main core (thread-safe WS broadcast)
        server->processSensorQueue();

        // Self-heal: revert an abandoned settings preview, watch the heap, then
        // service any pending reboot.
        server->checkPreviewTimeout();
        server->checkHeapHealth();
        server->checkReboot();
    }

    // Once the image has run for 60 s it has cleared setup() and is stable in
    // loop() — clear the boot-crash counter: crashes with a stable minute in
    // between are not a boot loop.
    static bool crashCounterCleared = false;
    if (!crashCounterCleared && millis() > 60000) {
        crashCounterCleared = true;
        Updater::bootCrashCounterReset();
    }

    // I6: WiFi reconnect (check every 30s, non-blocking background task)
    // connectStation() can block up to 49s (3x15s + backoff) which exceeds
    // the 30s WDT timeout. Running it in a background task prevents WDT panic.
    //
    // BLOCKER 4: After 3 consecutive reconnect failures, fall back to AP mode
    // so the patient's caregivers can reach the device (e.g. router down,
    // password changed at patient's home). Without this fallback the device
    // loops forever in disconnected STA mode with no usable interface.
    static unsigned long lastWifiCheck = 0;
    static std::atomic<bool> wifiReconnecting{false};
    static std::atomic<int> wifiFailCount{0};
    if (millis() - lastWifiCheck > 30000 && !wifiReconnecting) {
        lastWifiCheck = millis();
        if (wifi.mode == "station" && WiFi.status() != WL_CONNECTED) {
            wifiReconnecting = true;
            WifiLog::log(String("event=disconnected uptime_s=") + (unsigned long)(millis() / 1000));
            if (xTaskCreate([](void* param) {
                Serial.println("  WiFi lost, reconnecting...");
                WiFiManager* w = static_cast<WiFiManager*>(param);
                unsigned long reconStart = millis();
                String ip = w->connectStation();
                if (ip.length() > 0) {
                    wifiFailCount = 0;  // success — reset counter
                    WifiLog::log(String("event=reconnected ms=") +
                                 (unsigned long)(millis() - reconStart));
                } else {
                    int c = wifiFailCount.fetch_add(1) + 1;
                    Serial.printf("  WiFi reconnect failed (%d/3)\n", c);
                    if (c >= 3) {
                        Serial.println("  Max reconnect failures — falling back to AP mode");
                        WifiLog::log("event=ap_fallback attempts_failed=15 trigger=reconnect_loop");
                        w->startAP();
                        wifiFailCount = 0;
                        // Give carers the full hotspot window before the first
                        // recovery probe takes the radio again.
                        lastApRetry = millis();
                    }
                }
                wifiReconnecting = false;
                vTaskDelete(nullptr);
            }, "wifi_recon", 6144, &wifi, 1, nullptr) != pdPASS) {
                // A failed task creation used to leave wifiReconnecting latched
                // true, which silently disabled reconnect, AP fallback AND the
                // recovery probe below — the device would sit unreachable until
                // someone power-cycled it, and the carers cannot diagnose that.
                Serial.println("  FEHLER: Task wifi_recon nicht erstellbar");
                WifiLog::log("event=task_create_failed task=wifi_recon");
                wifiReconnecting = false;
            }
        } else if (wifi.mode == "station" && WiFi.status() == WL_CONNECTED) {
            wifiFailCount = 0;  // connection is fine
        }
    }

    // BLOCKER 4 (recovery): the AP fallback above is a one-way latch — once
    // mode is "ap" the station-reconnect branch never runs again, so a
    // transient router outage (reboot / brief power cut at the patient's home)
    // would strand the device on its hotspot until someone power-cycles it, and
    // the caregivers there cannot re-provision. Keep probing station in the
    // background so it self-heals. Slower cadence than the 30s health check:
    // each attempt briefly cycles the radio, so we accept a short hotspot blip
    // every few minutes rather than every 30s. connectStation() restores
    // mode="station"+ip on success; on failure it leaves the radio without the
    // AP, so we re-assert the hotspot to keep the caregiver interface up. Gated
    // on stored credentials — an unprovisioned device is meant to stay in AP.
    if (wifi.mode == "ap" && !wifiReconnecting && wifi.ssid.length() > 0 &&
        millis() - lastApRetry > 5UL * 60 * 1000) {
        lastApRetry = millis();
        wifiReconnecting = true;
        WifiLog::log("event=ap_recovery_probe");
        if (xTaskCreate([](void* param) {
            WiFiManager* w = static_cast<WiFiManager*>(param);
            // Only 2 attempts (not the cold-boot 5): this fires every 5 min while
            // the caretaker is on the hotspot, and the full cascade tied up the
            // radio for ~100 s each time. The scan still runs, so a router back
            // on a new BSSID is still found; it just recovers over a couple of
            // probes instead of hammering on the first.
            String ip = w->connectStation(15000, 2);
            if (ip.length() > 0) {
                Serial.printf("  AP-Recovery: Station wieder verbunden (%s)\n", ip.c_str());
                WifiLog::log(String("event=ap_recovery_ok ip=") + ip);
                // connectStation() already restored mode="station" + ip.
            } else {
                Serial.println("  AP-Recovery: weiterhin Hotspot");
                WifiLog::log("event=ap_recovery_fail");
                w->startAP();  // re-assert hotspot until the next probe
            }
            wifiReconnecting = false;
            vTaskDelete(nullptr);
        }, "ap_recover", 6144, &wifi, 1, nullptr) != pdPASS) {
            Serial.println("  FEHLER: Task ap_recover nicht erstellbar");
            WifiLog::log("event=task_create_failed task=ap_recover");
            wifiReconnecting = false;
        }
    }

    // AP-down retry, INDEPENDENT of credentials. The probe above is gated on
    // stored credentials, and startAP() sets mode="ap" even when softAP() failed
    // and the IP is 0.0.0.0. So an UNPROVISIONED device whose hotspot failed to
    // come up has no interface and nothing retries it — a dead device needing a
    // power-cycle. Re-assert the AP whenever we are in AP mode with no AP IP.
    static unsigned long lastApDownCheck = 0;
    if (wifi.mode == "ap" && !wifiReconnecting &&
        millis() - lastApDownCheck > 30000 &&
        WiFi.softAPIP().toString() == "0.0.0.0") {
        lastApDownCheck = millis();
        Serial.println("  AP ist unten (IP 0.0.0.0) — Hotspot neu starten");
        WifiLog::log("event=ap_down_retry");
        wifi.startAP();
    }
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

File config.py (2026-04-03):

# config.py — MundMaus shared configuration
# Board detection + constants used by all modules

import os
import sys

# ============================================================
# BOARD DETECTION
# ============================================================

_machine_id = getattr(sys.implementation, '_machine', '')

if 'ESP32S3' in _machine_id:
    BOARD = 'ESP32-S3'
    PIN_VRX       = 1
    PIN_VRY       = 2
    PIN_SW        = 42
    PIN_PUFF_DATA = 4
    PIN_PUFF_CLK  = 5
    PIN_DISP_A0   = 6
    PIN_DISP_RST  = 14
    PIN_DISP_CS   = 17
    PIN_DISP_SCK  = 18
    PIN_DISP_SDA  = 23
else:
    BOARD = 'ESP32-WROOM'
    PIN_VRX       = 33
    PIN_VRY       = 35
    PIN_SW        = 21
    PIN_PUFF_DATA = 32
    PIN_PUFF_CLK  = 25
    PIN_DISP_A0   = 2
    PIN_DISP_RST  = 14
    PIN_DISP_CS   = 17
    PIN_DISP_SCK  = 18
    PIN_DISP_SDA  = 23

# ============================================================
# CONFIGURATION
# ============================================================

VERSION = '3.3'

WS_PORT = 81
HTTP_PORT = 80

# AP Hotspot
AP_SSID = 'MundMaus'
AP_PASS = 'mundmaus1'
AP_IP = '192.168.4.1'

# Credentials file
WIFI_CONFIG_FILE = 'wifi.json'

# Joystick
DEADZONE = 150
NAV_THRESHOLD = 450
NAV_REPEAT_MS = 400
CALIBRATION_SAMPLES = 50

# Puff
PUFF_COOLDOWN_MS = 400
PUFF_RAW_THRESHOLD = 75000


# Display
USE_DISPLAY = False

# File serving
WWW_DIR = 'www'

# Timing
RECAL_IDLE_MS = 10000
PUFF_SEND_INTERVAL_MS = 100
SENSOR_POLL_MS = 20


# OTA
OTA_BASE_URL = 'https://mundmaus.de/ota'
OTA_AUTH = ''  # Base64 user:pass — set in ota_auth.py (gitignored)
try:
    from ota_auth import OTA_AUTH as _a
    OTA_AUTH = _a
except:
    pass
VERSIONS_FILE = 'versions.json'
UPDATE_STATE_FILE = 'update_state.json'

# ============================================================
# RUNTIME CONFIG (live-adjustable via Settings UI)
# ============================================================

CONFIGURABLE_KEYS = [
    'DEADZONE', 'NAV_THRESHOLD', 'NAV_REPEAT_MS',
    'PUFF_COOLDOWN_MS', 'PUFF_RAW_THRESHOLD',
    'SENSOR_POLL_MS',
]

DEFAULTS = {k: globals()[k] for k in CONFIGURABLE_KEYS}

_RANGES = {
    'DEADZONE': (10, 1000),
    'NAV_THRESHOLD': (100, 2000),
    'NAV_REPEAT_MS': (50, 2000),
    'PUFF_COOLDOWN_MS': (50, 5000),
    'PUFF_RAW_THRESHOLD': (10000, 200000),
    'SENSOR_POLL_MS': (5, 500),
}

def update(key, value):
    """Update a config value at runtime (RAM only, not persisted)."""
    if key not in CONFIGURABLE_KEYS:
        return
    if not isinstance(value, (int, float)):
        return
    lo, hi = _RANGES.get(key, (0, 100000))
    globals()[key] = int(max(lo, min(hi, value)))

def get_all():
    """Return dict of all configurable values."""
    return {k: globals()[k] for k in CONFIGURABLE_KEYS}

def get_saved():
    """Return only non-default values from settings.json."""
    import json
    try:
        with open('settings.json') as f:
            return json.load(f)
    except:
        return {}

def save(values):
    """Write non-default values to settings.json (atomic via temp file)."""
    import json
    diff = {k: v for k, v in values.items()
            if k in CONFIGURABLE_KEYS and v != DEFAULTS[k]}
    with open('settings.tmp', 'w') as f:
        json.dump(diff, f)
    try:
        os.remove('settings.json')
    except OSError:
        pass
    os.rename('settings.tmp', 'settings.json')

def reset():
    """Delete settings.json and restore all defaults in RAM."""
    for k in CONFIGURABLE_KEYS:
        globals()[k] = DEFAULTS[k]
    try:
        os.remove('settings.json')
    except OSError:
        pass

# Load saved settings at import time
try:
    import json as _json
    with open('settings.json') as _f:
        for _k, _v in _json.load(_f).items():
            if _k in CONFIGURABLE_KEYS:
                globals()[_k] = _v
except:
    pass

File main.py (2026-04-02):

# main.py — MundMaus ESP32 Firmware v3.1
# Thin orchestrator: imports modules, runs async event loop.

import gc
import os
import sys
import time

import machine

try:
    import asyncio
except ImportError:
    import uasyncio as asyncio

import config
from config import (
    AP_PASS,
    AP_SSID,
    BOARD,

    PIN_PUFF_CLK,
    PIN_PUFF_DATA,
    PIN_SW,
    PIN_VRX,
    PIN_VRY,
    PUFF_SEND_INTERVAL_MS,
    RECAL_IDLE_MS,

    UPDATE_STATE_FILE,
    VERSION,
    WWW_DIR,
)
from display import display_status, init_display
from sensors import CalibratedJoystick, PuffSensor
from server import MundMausServer
from wifi_manager import WiFiManager

# ============================================================
# ASYNC TASKS
# ============================================================

async def sensor_loop(joystick, puff, server):
    idle_start = time.ticks_ms()
    last_recal = time.ticks_ms()
    last_puff_send = 0

    while True:
        try:
            now = time.ticks_ms()

            nav = joystick.poll_navigation()
            if nav:
                server.send_nav(nav)
                idle_start = now

            if joystick.poll_button():
                server.send_action('press')
                idle_start = now

            if puff:
                puff.poll()
                if time.ticks_diff(now, last_puff_send) > PUFF_SEND_INTERVAL_MS:
                    level = puff.get_level()
                    if level > 0.02:
                        server.send_puff_level(level)
                    last_puff_send = now
                if puff.detect_puff():
                    server.send_action('puff')
                    idle_start = now

            if joystick.is_idle():
                if time.ticks_diff(now, idle_start) > RECAL_IDLE_MS:
                    if time.ticks_diff(now, last_recal) > 60000:
                        joystick.calibrate(samples=20)
                        last_recal = now
                        idle_start = now
            else:
                idle_start = now
        except Exception as e:
            print(f"  sensor_loop: {e}")

        _heartbeat['sensor'] = time.ticks_ms()
        await asyncio.sleep_ms(config.SENSOR_POLL_MS)




async def server_loop(server, wifi, joystick=None, puff=None):
    while True:
        try:
            server.poll_http()
            server.poll_ws()

            for msg in server.ws_read_all():
                if msg.get('type') == 'wifi_config':
                    ssid = msg.get('ssid', '')
                    pw = msg.get('password', '')
                    if ssid:
                        wifi.save_credentials(ssid, pw)
                        server.ws_send_all({'type': 'wifi_status', 'status': 'saved',
                                            'ssid': ssid, 'message': 'Gespeichert. Neustart...'})
                        await asyncio.sleep_ms(2000)
                        machine.reset()
                elif msg.get('type') == 'wifi_scan':
                    server.ws_send_all({'type': 'wifi_networks',
                                        'networks': wifi.scan_networks()})
                elif msg.get('type') == 'config_preview':
                    key = msg.get('key', '')
                    val = msg.get('value')
                    if key and val is not None:
                        config.update(key, val)
                elif msg.get('type') == 'config_save':
                    try:
                        config.save(config.get_all())
                        server.ws_send_all({'type': 'config_saved', 'ok': True})
                    except Exception as e:
                        server.ws_send_all({'type': 'config_saved', 'ok': False, 'error': str(e)})
                elif msg.get('type') == 'config_reset':
                    config.reset()
                    server.ws_send_all({'type': 'config_values',
                                        'current': config.get_all(),
                                        'defaults': config.DEFAULTS,
                                        'saved': {}})
                elif msg.get('type') == 'calibrate':
                    result = {'type': 'calibrate_done'}
                    if joystick:
                        joystick.calibrate()
                        result['joy_center'] = [joystick.center_x, joystick.center_y]
                    if puff:
                        puff.calibrate_baseline()
                        result['puff_baseline'] = puff.baseline
                    server.ws_send_all(result)

            server.check_reboot()

        except Exception as e:
            print(f"  server_loop: {e}")

        _heartbeat['server'] = time.ticks_ms()
        await asyncio.sleep_ms(10)


async def wifi_monitor(wifi):
    """Reconnect WiFi if connection drops. Essential for remote deployment."""
    while True:
        await asyncio.sleep_ms(30000)
        if wifi.mode == 'station' and not wifi.sta.isconnected():
            print("  WiFi verloren, reconnect...")
            ip = wifi.connect_station()
            if ip:
                print(f"  WiFi reconnected: {ip}")
            else:
                print("  WiFi reconnect fehlgeschlagen, retry in 30s")


_heartbeat = {'sensor': 0, 'server': 0}

async def watchdog_feed(wdt):
    """Feed hardware watchdog only if both sensor_loop and server_loop are alive."""
    while True:
        now = time.ticks_ms()
        sensor_age = time.ticks_diff(now, _heartbeat['sensor'])
        server_age = time.ticks_diff(now, _heartbeat['server'])
        if sensor_age < 30000 and server_age < 30000:
            wdt.feed()
        else:
            print(f"  WDT: NOT feeding (sensor={sensor_age}ms, server={server_age}ms)")
        await asyncio.sleep_ms(10000)


async def display_loop(tft, ip, mode, joystick, puff, server):
    while True:
        display_status(tft, ip, mode,
                       (joystick.center_x, joystick.center_y),
                       puff.baseline if puff else 0,
                       len(server.ws_clients))
        await asyncio.sleep_ms(5000)


# ============================================================
# MAIN
# ============================================================
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

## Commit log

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2026-03-03 fix(lint): auto-fix ruff violations in MicroPython firmware
    Fixes: unused imports, unsorted imports, invalid escape sequences.
    [boot.py, main.py]
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2026-03-05 feat(enclosure): add MundMaus v5.1 corrected landscape enclosure
    Key corrections vs v5:
    - ESP32-WROOM-32 DevKitC V4 (Micro-USB 8x3mm, not USB-C)
    - Hex nut pocket 14.7mm SW (correct 0.4mm tolerance)
    - Joystick now 3.1mm above lid (was 4.4mm below)
    - Cable exit notches (8x4mm) on both side walls
    [mundmaus_v51_base.stl, mundmaus_v51_lid.stl]
2026-03-05 chore(enclosure): remove v5 and v5.1 — mount position wrong
    Both versions had the schwanenhals mount on the top (+Y wall) instead
    of the right short side (+X wall). v5.2 with correct placement pending.
    [mundmaus_v51_base.stl, mundmaus_v51_lid.stl, mundmaus_v5_base.stl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]
2026-03-05 feat(enclosure): add v5.2 — mount relocated to right short side (+X wall)
    Schwanenhals mount moved from +Y (top) to +X (right short side).
    USB cutout moved to +Y wall. ESP32 shifted left for collar clearance.
    Dimensions unchanged: 136x50x41mm. CadQuery source + STLs + SVGs.
    [mundmaus_v52_base.stl, mundmaus_v52_lid.stl]
2026-03-06 feat(enclosure): MundMaus v5.3 — USB-C panel mount redesign
    - Removed old rectangular USB cable exit on +Y wall
    - Added 8.5mm USB-C panel mount hole with 12mm counter-nut recess
    - Added two C-shaped cable clips on floor (strain relief + routing)
    - CadQuery 2.7.0, zero build errors
    [mundmaus_v53_base.stl, mundmaus_v53_lid.stl]
2026-03-07 feat(enclosure): MundMaus v5.4 — USB-C adapter bay, snap clips removed
    - USB bay extended +25mm on +X side for USB-C adapter clearance
    - USB-C opening 12×7mm with strain relief channel
    - Snap clips removed (broke during assembly), replaced with screw posts
    - 4 preview renders: assembly, top, side, back
    [mundmaus_v54_enclosure.scad]
2026-03-08 feat(enclosure): MundMaus v5.4 — adapter bay redesign (CadQuery)
    Replaces v5.3 panel-mount with asymmetric +X adapter bay (32mm).
    ESP32 at X=28, 17mm clearance, capture hood + rails for adapter retention.
    Gooseneck mount moved to +Y wall. STLs + 4 renders included.
    [mundmaus_v54_base.stl, mundmaus_v54_lid.stl]
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2026-03-08 chore(enclosure): remove old v5.2, v5.3 and stale v5.4 scad file
    Only v5.4 CadQuery files remain (current version with mount on -X short wall).
    [mundmaus_v52_base.stl, mundmaus_v52_lid.stl, mundmaus_v53_base.stl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]
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2026-03-08 feat(enclosure): v5.4c — pressure sensor side mount, joystick upper edge, mic mount fix
    - Joystick moved to upper +Y edge (JOY_POS_Y=10.8) for max sight clearance
    - Pressure sensor mounted at +Y inner wall with barb hole for external tube
    - Old tube feedthrough and pressure ledge removed (tube runs outside)
    - Fix OCCT coplanar-face boolean failure in mic mount collar union (0.5mm overlap)
    - Vent slots on -Y wall, barb port on +Y wall (no collision)
    [mundmaus_v54_base.stl, mundmaus_v54_lid.stl]
2026-03-08 fix(enclosure): clamp joystick platform to cavity wall, skip wall-zone pins
    Front platform block was protruding 1.6mm past +Y inner wall (Y=23.6 vs wall at Y=22).
    Now clamped to Y=21.8 with 0.2mm clearance. Pins in wall relief zone skipped.
    [mundmaus_v54_base.stl]
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2026-03-08 fix(enclosure): joystick platform boolean fix + v5.4c report update
    Fix OCCT coplanar-face boolean failure that caused joystick platform
    to disappear from STL. Sequential union without combined fillet,
    0.5mm floor overlap. Update report and write_report() to v5.4c with
    pressure sensor, joystick position, and pneumatic path changes.
    [mundmaus_v54_base.stl]
2026-03-09 fix(enclosure): lid Y-offset from rotateAboutCenter
    Replace rotateAboutCenter with explicit rotate around Y=0 to prevent
    0.53mm Y-shift caused by asymmetric features (text). Both base and lid
    now have identical XY footprint: 168.00 x 50.00 mm.
    [mundmaus_v54_lid.stl]
2026-03-09 fix(enclosure): move joystick from Y=10.8 to Y=8.0 for better clearance
    PCB no longer overhangs into +Y wall — no wall relief needed.
    Front platform block at full 6mm (was clamped to 4.2mm). Front pins
    now 3.5mm from wall (was 0.7mm). Platform covers 24.8mm of 26mm PCB.
    [mundmaus_v54_base.stl, mundmaus_v54_lid.stl]
2026-03-09 fix(enclosure): barb hole 4.5→3.0mm for press-fit with 3mm sensor port
    Measured MPS20N0040D-S barb at 3mm. FDM shrinkage gives natural
    interference fit. Chamfer reduced 7.0→5.0mm proportionally.
    [mundmaus_v54_base.stl]
2026-03-09 fix(enclosure): barb hole on wrong wall — XZ workplane normal is -Y
    Workplane("XZ") normal points -Y, so offset must be negated to reach
    the +Y wall. Barb hole and chamfer were cutting through -Y wall
    (vent side) instead of +Y wall (joystick/bracket side). Fixed by
    negating offset signs.
    [mundmaus_v54_base.stl]
2026-03-09 feat(enclosure): v5.5 — compact symmetric layout, no adapter bay
    Rearrange components: Mount(-X) → ESP32 → Joystick → Sensor(+X).
    Remove adapter bay, shrink from 168mm to 136mm symmetric shell.
    USB cable notch on -Y wall with lid strain relief. Fix vent slot
    wall direction (was +Y, now correctly -Y).
    [mundmaus_v55_base.stl, mundmaus_v55_lid.stl]
2026-03-09 fix(enclosure): v5.5 — joystick clearance, end stop removal, USB plug channel
    Three fixes based on first print feedback:
    - JOY_POS_Y 8.0→5.0: more clearance to +Y wall for assembly
    - Removed ESP32 end stop wall (guide rails sufficient)
    - Added USB plug channel in joystick platform for Micro-B access
    [mundmaus_v55_base.stl, mundmaus_v55_lid.stl]
2026-03-09 fix(enclosure): v5.5 — pin support, boss removal, ESP32 fit
    Three fixes from second print test:
    - Widen joystick front block (26→34mm) so +Y pins sit on platform
    - Remove +X+Y screw boss for pressure sensor cable clearance
    - ESP32 guide rails shorter (55→40%), wider tolerance (0.3→0.5mm)
    [mundmaus_v55_base.stl, mundmaus_v55_lid.stl]
2026-03-09 fix(enclosure): v5.5 — remove sensor U-bracket, shelf only
    U-bracket side rails intersected corner fillet creating a hole.
    Simplified to flat shelf — sensor sits on ledge, +Y wall as backstop,
    lid retains from above.
    [mundmaus_v55_base.stl]
2026-03-09 fix(enclosure): v5.5 — inner corner radius 2.5→9mm for uniform wall
    INNER_R must be CORNER_R - WALL (12-3=9) to maintain 3mm wall
    thickness at corners. Previous 2.5mm left only ~0.3mm at diagonals.
    [mundmaus_v55_base.stl, mundmaus_v55_lid.stl]
2026-03-19 feat: solitaire UX fixes, enclosure v5.5 redesign, P2S direct printing
    Solitaire:
    - Fix key-repeat bug causing immediate card deselect (e.repeat guard)
    - Add navigable action buttons (Hilfe/Neu) right of tableau
    - Move WiFi icon into status bar, remove old hint toggle
    - Add puff indicator icon, bigger stats text
    - Single cursor bar below card rows
    Enclosure v5.5:
    - Correct ESP32 DevKitC V4 dimensions (54.4mm, Espressif spec)
    - Correct KY-023 mounting hole grid (26.67×20.32mm)
    - New layout: Mount(-X) → Joy(X=8) → Sensor(X=42) → ESP32(X=35)
    - 4 pillar feet (Ø8/11mm) instead of solid platform — USB cable access
    - Joystick centered on ESP32 USB port for plug access between pillars
    - 2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
    [machine-resolved.json, mundmaus_v55_base.stl, mundmaus_v55_lid.stl]
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2026-03-19 fix(enclosure): v5.5 — 4 pillars, USB cable routing, final layout
    - Revert to proven layout: Joy(X=-19) → ESP32(X=35) → Sensor(X=42)
    - Restore all 4 joystick pillars (USB cable routes between feet)
    - Assembly order: plug USB → seat ESP32 → route cable → mount joystick
    - Add annotated top-view schematic (PIL-generated)
    - Lower-right pillar near USB plug Y-range but 13.5mm X-gap:
    flexible cable bends around pillar, stecker stays clear
    - Validate: 0 errors, all clearances OK
    [mundmaus_v55_base.stl, mundmaus_v55_lid.stl]
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2026-03-20 fix(enclosure): v5.5 — Ø6mm pillars, Y=-2 centered on USB, 1.7mm clearance
    - Pillar shaft Ø8→Ø6mm, flare Ø11→Ø9mm for USB plug clearance
    - JOY_POS_Y=−2 centers pillars on USB port Y for equal 1.7mm gap both sides
    - USB Micro-B plug (11mm wide) fits between pillars (14.3mm inner gap)
    [mundmaus_v55_base.stl, mundmaus_v55_lid.stl]
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2026-03-20 fix(enclosure): ESP32 flipped for cooling, reset hole, no lid text
    - ESP32 upside down: WROOM module faces floor for heat dissipation
    - Standoff 0.5mm, EN reset Ø3mm hole in floor
    - Lid text removed (caused slicer surface failure)
    [mundmaus_v55_base.stl, mundmaus_v55_lid.stl]
2026-03-21 fix(enclosure): WROOM collar, EN button position, tighter guide rails
    - WROOM: 16×18mm hole with raised collar, standoff 3mm
    - EN reset hole: fixed Y-side (+Y→-Y, was 18mm off), distance 7.5mm from USB
    - Guide rails: TOL_LOOSE 0.5→0.2mm for press-fit
    - Lid: ESP32 hold-down pads to keep board seated
    [mundmaus_v55_base.stl, mundmaus_v55_lid.stl]
2026-03-21 fix(enclosure): lid printability — continuous inner wall, no overhangs
    - Remove ESP32 hold-down pads (disconnected geometry caused spaghetti)
    - Remove joystick hold-down stubs (same issue)
    - LID_TOP_R 3.5→1.5mm (was creating paper-thin walls in fillet zone)
    - Extend lip wall from ceiling to lip bottom — eliminates overhang at
    Z=9mm where lip previously started floating in air
    - Switch slicer to Arachne wall generator (consistent wall fill,
    fixes gap infill inconsistency with classic generator on 2mm walls)
    - Add retraction validation to profile check
    - Regenerate STL + renders
    [mundmaus_v55_base.stl, mundmaus_v55_lid.stl]
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2026-03-27 feat(enclosure): detent-ridge retention, circular joystick hole, platform lower
    Replace failed cantilever snap-clips with Tupperware-style detent ridge:
    - 0.5mm ridge pads at 7 discrete points on lid lip (incl. joystick area)
    - 0.55mm groove pads at matching positions in base cavity wall
    - Discrete pads allow local wall flex → stronger click than continuous ridge
    Joystick lid opening: square 16.3mm → circular 14mm with calculated offset
    (X=+1.1, Y=-0.8) to match measured housing position. 2mm exterior chamfer.
    Platform height 21.5→21.0mm per user feedback.
    Validator updated: groove-direction guard, ridge/groove checks.
    Visual clearance check updated for new retention system.
    Co-Aut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
    [mundmaus_v55_base.stl, mundmaus_v55_lid.stl]
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2026-03-29 feat: consistent game UI, mundmaus.de website, WiFi panel in portal
    Games (chess, memory, solitaire):
    - Dark navy theme across all three games
    - Gold cursor (#FFD700) with background overlay — consistent
    - WCAG AA contrast: darkened memory symbols, chess piece strokes
    - Filled chess pieces (both colors use solid Unicode glyphs)
    - Chess board: tan/sage-green instead of blue/beige
    - Buttons (Neu, Zurück) on RIGHT side of game board
    - Header: game name + stats (gold values) + WS indicator dot
    - Footer: consistent kbd hints for caregivers (arrow keys, space, N, K)
    - Kiosk mode (K) = fullscreen + hide hints + idle screen
    - WebSocket exponential backoff (3s→30s cap)
    - Chess: navigable undo bu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
    [main.py]
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2026-03-29 feat: boot.py with update rollback + recovery AP
    Replaces 16-line boot.py with ~160-line safety net: reads
    update_state.json on every boot, rolls back .bak files after 2 failed
    update attempts, and falls back to a minimal recovery AP with file
    upload UI when no backups exist. Also adds I001 ignore for boot.py in
    pyproject.toml (intentional MicroPython interleaved-import pattern).
    [boot.py]
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2026-03-29 fix: restore original sensor/wifi behavior — revert unintended changes during extraction
    Modularization into sensors.py and wifi_manager.py introduced behavioral
    deviations from the original main.py. This restores exact original behavior:
    sensors.py:
    - PuffSensor: restore max_range normalization (was dividing by baseline)
    - PuffSensor: restore busy-loop timeout returning 0 (was time-based returning None)
    - PuffSensor: restore clock timing with sleep_us(1) and correct read order
    - PuffSensor: restore 100ms startup delay before calibration
    - PuffSensor: restore 20ms calibration interval (was 10ms)
    - CalibratedJoystick: restore ADC WIDTH_12BIT setting
    - CalibratedJoystick: restore 10 warm-up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
    [sensors.py, wifi_manager.py]
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2026-03-29 fix: address code review — HTTP status, path traversal, async update, error handling
    - C1: Add HTTP status check to _http_get (match _download_file pattern)
    - C2: Path traversal protection in Recovery AP upload handler
    - C3: Move update execution to async task so server_loop stays responsive
    - I2: Add error_cb parameter to run_update, wire update_error WS messages
    - I3: Wrap firmware rename in try/except with rollback on failure
    - I5: Add 4KB max header size limit to both HTTP functions
    [boot.py, main.py, updater.py]
2026-03-29 fix: boot.py forward ref, async update try/finally, .bak cleanup
    - Move _recovery_ap() definition before module-level code (was NameError)
    - Wrap _run_update_async in try/except/finally (prevents flag leak)
    - Clean up .bak files after successful boot (prevents flash bloat)
    [boot.py, main.py]
2026-03-29 fix: iteration 3 — body limit, socket leak, async yields, WS reconnect, Content-Length
    Critical: _http_get body 16KB cap, SSL raw_sock leak fix in both
    HTTP functions, run_update made async with sleep_ms(0) yields.
    Important: portal WS auto-reconnect, update_error JS handler,
    Content-Length uses byte length, recovery flag clearing, empty
    download validation. Minor: loop_count reset, tighter HTTP 200
    check, boot.py hardcoding comment.
    [boot.py, main.py, server.py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]
2026-03-29 fix: iteration 4 — corrupt JSON handling, socket init consistency
    - _mark_boot_ok catches ValueError for corrupt update_state.json
    - _download_file: socket init before try block (matches _http_get)
    [main.py, updater.py]
2026-03-29 fix: iteration 5 — pending-before-backup, Content-Length verify, re-check endpoint
    - C1: Write update_state.json BEFORE destructive backup/rename operations
    - C2: Verify downloaded file size against Content-Length header
    - I1: Replace em-dash with ASCII hyphen in portal, compute byte-correct Content-Length
    - I2: Catch ValueError in _load_versions for corrupt JSON
    - I4: Add POST /api/updates/check re-check endpoint + portal button
    - I5: Send update state and updating flag on WS connect
    [main.py, server.py, updater.py]
2026-03-29 fix: setup page Content-Length bytes, re-check delay only on boot, guard re-check during update
    [main.py, server.py]
2026-03-29 fix: iteration 7 — status phrases, 404 Content-Length, binary recovery, WS cleanup, boot logic
    - _send_json: correct reason phrases for 400/500 instead of "OK"
    - _send_404: add Content-Length header, encode body once
    - boot.py recovery AP: keep request as bytes to avoid binary corruption
    - ws_read_all: detect empty recv and close frames to clean dead connections
    - _run_update_async: guard against None _update_info
    - _mark_boot_ok: single write instead of potential double-write
    [boot.py, main.py, server.py]
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2026-03-30 fix: replace str.title() with MicroPython-compatible capitalization
    MicroPython does not support str.title() — use manual upper() on first char.
    [server.py]
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2026-03-30 feat: WiFi signal strength, sensor status in portal, robust update check
    - WiFi RSSI with label (Perfekt/Gut/Schwach/Sehr schwach) in portal header
    - Sensor status (Joystick/Puff) in portal footer
    - Update check waits for WiFi connectivity (up to 10s) instead of fixed 2s delay
    [main.py, server.py, wifi_manager.py]
2026-03-30 fix: friendlier update UI texts for non-technical users
    - 'Aktuell' → 'Alles auf dem neuesten Stand'
    - 'Update(s) verfuegbar' → 'X Verbesserung(en) verfuegbar'
    - 'Offline' → 'Keine Internetverbindung'
    - 'Jetzt aktualisieren' → 'Jetzt installieren'
    - Section title 'Updates' → 'Software'
    [server.py]
2026-03-30 fix: portal fetches update status via HTTP on load, not just WS
    WS push can arrive before JS connects. Fetch /api/updates on page load as fallback.
    [server.py]
2026-03-30 fix: DNS probe before update check, WS status dot, retry on offline
    - Wait for actual DNS resolution (mundmaus.de) instead of just isconnected()
    - Green/red dot in footer shows WebSocket connection status
    - 'Keine Internetverbindung' shows 'Nochmal pruefen' button
    [main.py, server.py]
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2026-03-30 feat: refresh update status on WS reconnect
    After ESP32 reboot, WS reconnects and re-fetches /api/updates to show current state.
    [server.py]
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2026-03-30 feat: auto-reload page after ESP32 reboot (>10s disconnect)
    Browser detects long WS disconnect. On reconnect after >10s, reloads entire page
    to get fresh portal HTML (e.g. after OTA firmware update).
    [server.py]
2026-03-30 feat: robustness hardening for remote deployment
    CRITICAL fixes:
    - Remove boot.py from OTA manifest — never OTA-update the safety net
    - Hardware watchdog (WDT 60s) — resets device if asyncio deadlocks
    - WiFi auto-reconnect every 30s — survives router reboots
    - boot.py _write_state wrapped in try/except — flash-full won't crash boot
    - boot.py _rollback wrapped in try/except — filesystem errors handled
    - updater.py: don't delete state file after failed rollback
    IMPORTANT fixes:
    - sensor_loop + server_loop wrapped in try/except — resilient to transient errors
    - _mark_boot_ok: write state BEFORE deleting .bak files
    - Remove decoded OTA password from config.py comment
    - Reduce DNS pr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
    [boot.py, config.py, main.py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]
2026-03-30 fix: gc.collect() before SSL handshake — prevents OOM during update check
    SSL needs ~20KB RAM. With all tasks running, free RAM drops to ~65KB.
    gc.collect() before each HTTPS connection frees enough for the handshake.
    [main.py, updater.py]
2026-03-30 fix: run OTA check BEFORE launching tasks — SSL needs max RAM
    SSL handshake needs ~30KB. With all async tasks running, only ~60KB free.
    Now check runs synchronously after server.start() but before task launch,
    when ~100KB is available. Tasks start after check completes.
    [main.py, updater.py]
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2026-03-30 fix: retry manifest check 3x with 5s delay — handles SSL warmup on weak WiFi
    [main.py]
2026-03-30 fix: run OTA check synchronously BEFORE asyncio.run()
    SSL handshake and asyncio conflict on ESP32 — mbedtls fails with error 16
    when asyncio event loop is running. Move check to main() before asyncio starts.
    WiFi connects in _check_updates_sync(), async_main reuses the connection.
    [main.py]
2026-03-30 fix: iteration 9 — rollback os.remove, WDT before OTA, reduce stall, cleanup
    - boot.py _rollback: os.remove(orig) before os.rename (FAT compatibility)
    - WDT started in main() before _check_updates_sync (protects SSL stalls)
    - Retries reduced to 2 (max ~36s stall instead of 54s)
    - try/except around check_manifest in _check_updates_sync
    - Dead code removed: update_check initial param + DNS probe
    - _update_task_running initialized in MundMausServer.__init__
    [boot.py, main.py, server.py]
2026-03-30 fix: WiFi scan progress indicator, WS chip shows Getrennt/Verbunden
    - 'Suche Netzwerke...' while scanning, 'X Netzwerke gefunden' when done
    - WS chip text changes to 'Getrennt' on disconnect, 'Verbunden' on reconnect
    [server.py]
2026-03-30 fix: scan results below search button, WS chip → Erreichbar/Nicht erreichbar
    - Moved network scan dropdown + status below search button, above SSID input
    - WS chip: 'Erreichbar' (green) when device reachable, 'Nicht erreichbar' (red) when not
    - Clearer semantics: chip shows device availability, not game connection
    [server.py]
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2026-03-30 fix: Portal button navigable in all games, no-cache headers
    - Chess: btn-back action handler (btnCursor===2) added
    - Memory: full button column navigation (up/down between Neu/Portal), action dispatch
    - Server: Cache-Control changed to no-cache (was max-age=3600 causing stale game files)
    [server.py]
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2026-03-30 fix: increase WDT timeout to 120s — SSL check can take >60s on weak WiFi
    [main.py]
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2026-03-30 fix: frontend review — WS backoff, cursor, undo shortcut, kiosk class, portal hints
    Solitaire: exponential WS backoff (was fixed 3s), cursor visible for caregivers,
    U key for undo, kiosk-mode→kiosk class, tabular-nums on stats.
    Memory: remove duplicate font-variant-numeric.
    Chess: ESC goes to portal when no piece selected.
    Portal: keyboard hint footer for caregivers.
    [server.py]
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2026-03-30 feat: golden M favicon on all pages — SVG data URI, no extra file
    Dark navy rounded square with gold 'M'. Embedded as data URI in HTML head.
    Also fixes solitaire title to 'MundMaus Solitaer' (was 'Solitär – Mundmaus').
    [server.py]
2026-03-30 fix: rename Memory → Memo (Ravensburger trademark), Solitaer in portal
    memory.html: all user-facing text changed to 'Memo'.
    Portal: name mapping for known games (memory→Memo, solitaire→Solitaer).
    [server.py]
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2026-03-30 fix: re-check button triggers reboot instead of in-flight SSL
    SSL and asyncio conflict on ESP32 — HTTPS calls hang the event loop.
    Re-check now reboots device, which runs the OTA check before asyncio starts.
    Removed dead update_check async function and _recheck_updates flag.
    [main.py, server.py]
2026-03-30 fix: ALL SSL operations run before asyncio — no more hangs
    SSL and asyncio fundamentally conflict on ESP32 (mbedtls error 16).
    Solution: ALL network operations (check + download + install) run
    synchronously in main() BEFORE asyncio.run().
    - 'Jetzt installieren' button sets _do_update flag file + reboots
    - On boot, _check_and_install_updates_sync reads flag + runs install
    - run_update changed from async to sync (no more await/yield)
    - Removed _run_update_async, _updating, _update_task_running
    - Portal shows progress via serial during boot install
    [main.py, server.py, updater.py]
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2026-03-30 feat(solitaire): universal icons — buttons, footer, stats, messages
    Replace German text with universal icons/symbols throughout: action
    buttons (? for hints, NEW badge, 🏠 for portal), footer keyboard hints,
    stat labels (# and ★), win/auto-solve messages, idle screen, and WS
    status indicators.
    [server.py]
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2026-04-01 fix: ESP32 robustness — smart WDT, faster OTA, RAM protection
    - WDT: only feed watchdog if both sensor_loop and server_loop have
    heartbeated in the last 30s (detects hung loops, not just asyncio deadlocks)
    - OTA: single attempt instead of 2 retries, WiFi timeout 8s→15s,
    socket timeout 8s→15s/20s — boot ~20s faster on timeout
    - RAM: gc.collect() + reject with 503 if <20KB free before serving
    large files (prevents OOM during concurrent requests)
    [main.py, server.py, updater.py]
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2026-04-01 fix: settings not in game grid, shorter button labels
    - Exclude settings.html from game scan (was showing as duplicate "game")
    - Move settings link below game grid as separate text link
    - Shorten button labels to fit (icon + English only)
    [server.py]
2026-04-01 fix: hide software section when offline, deduplicate update logic
    - Offline OTA check no longer shows misleading "Restart" button
    - Software section only visible when updates available or up-to-date
    - Extracted showUpd() helper replacing 3 copies of inline update logic
    [server.py]
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
